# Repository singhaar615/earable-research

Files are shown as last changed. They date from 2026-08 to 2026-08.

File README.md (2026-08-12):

# Earable-Based Sleep Bruxism Detection

Research project developing a low-cost, in-ear wearable ("earable") system to detect and classify sleep bruxism (teeth grinding) using acoustic signal processing. The system captures grinding-related sound via an in-ear MEMS microphone, processes it on an Arduino, and analyzes it in MATLAB to flag grinding severity.

## Overview

Sleep bruxism is typically diagnosed via polysomnography (PSG), which is expensive, lab-based, and inconvenient for longitudinal monitoring. This project explores whether a simple in-ear acoustic sensor can achieve meaningful grinding detection outside a clinical setting: using nothing more than a MEMS microphone, an Arduino, and signal processing techniques adapted from PSG-based bruxism severity research.

The pipeline spans three layers:

- **Hardware**: an Arduino-based in-ear MEMS microphone rig for raw audio data collection
- **Signal processing**: MATLAB scripts for filtering, burst detection, and spectral analysis
- **Classification**: a lightweight warning algorithm that flags grinding events as No Warning / Mild / Severe

## Background & Motivation

Occlusion testing (mic near the jaw vs. mic sealed in-ear) showed that in-ear placement produced a substantially stronger grinding signal than external placement, so all subsequent data collection used in-ear placement.

Detection logic was informed by a review of PSG-based bruxism severity literature, whose burst-detection thresholds and two-factor severity structure (episode count vs. duration) shaped the design of this project's own detection algorithm.

### Key scripts

| Script | Purpose |
|---|---|
| `filtering_algorithm.m` | Detects teeth-grinding bursts from a single acoustic trial. Bandpasses the raw signal to the grinding band, builds an envelope, and flags "active" stretches using an adaptive baseline threshold, scoring each candidate burst on duty cycle and spectral flatness to reject non-grinding noise. Classifies the trial as No/Mild/Severe Warning based on burst count and duration, and plots the time-domain and frequency-domain (Welch PSD) views. |
| `silence_v_fan.m` | Compares the frequency spectrum of grinding recordings made in silence vs. with fan noise present. Concatenates matching Raw (or Filtered) columns per condition across multiple days, computes a Welch PSD for each, and plots the two spectra side by side to check for potential teeth grinding bands and whether fan noise masks or shifts the grinding signature. |
| `updated_fft.ino` | Arduino sketch that samples the earable's microphone at 5 kHz for 150 seconds, tracking a slowly-updating baseline (rolling average) to subtract out DC drift. Applies a fixed noise floor to the deviation from baseline and streams both the raw and processed values over serial as CSV. All data collected from this was used in filtering/analysis in MATLAB. |

## Known Limitations

- Detected grinding duration tracks the correct relative trend across severity tiers but is not numerically precise against ground-truth grinding time
- Classification accuracy has only been validated on a single subject; generalization to other users/ear geometries is untested
- Band selection (20–80 Hz) and thresholds were tuned empirically for this dataset and may need recalibration for other hardware or environments

## Status

This research project has concluded; the repository is preserved as a record of the methodology, pipeline, and findings.

## License

See [LICENSE](LICENSE) for details.

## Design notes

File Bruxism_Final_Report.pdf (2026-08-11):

## A Non-Invasive Acoustic Sensing System for Bruxism Screening

Aaruni Singh
Summer 2026; 2 Credit Hours Mentors: Dr. Saeed Mohammadi, Dr. Babak Ziaie

Abstract—Sleep bruxism (teeth grinding) is a common, frequently undiagnosed oral disorder, and is currently screened using expensive sleep labs or uncomfortable EMG-based devices. This study explores whether a low-cost, in-ear MEMS microphone can detect teeth grinding from acoustic signals and distinguish it from ambient noise. Occlusion-effect testing found that in-ear microphone placement increased grinding-signal amplitude by roughly 10× relative to a near-jaw placement. Using 30-minute grinding recordings under silence and fan noise, a 20–80 Hz frequency band was identified as unique with grinding after excluding peaks shared with non-grinding baseline recordings. A MATLAB-based filtering algorithm using envelope thresholding, gap-bridging, duty-cycle, and spectral-flatness criteria correctly classified all tested trials (3/3 No Warning, 3/3 Mild, 2/2 Severe) for a sample size of one (N = 1). Results support the feasibility of audio-only bruxism screening, though generalization beyond one subject and validation against polysomnography metrics remain future work.

I. INTRODUCTION
A. Background Information

Bruxism (teeth grinding) is a frequently undiagnosed oral disorder that can lead to serious dental damage, poor sleep, and long-term health issues.

- Bruxism (awake or sleep) affects an estimated 24% of adults and 19% of children.
- Sleep bruxism specifically affects an estimated 21% of the global population.

Common causes of bruxism include stress and anxiety, abnormal tooth alignment, certain medications, neurological conditions, and substance abuse. Symptoms include tooth wear and sensitivity, temporomandibular joint (TMJ) pain and stiffness, recurrent headaches or migraines, discomfort in biting or chewing, and poor sleep quality. If untreated over months or years, irreversible damage may occur.

Current diagnosis requires expensive overnight sleep lab stays (polysomnography, or PSG), and existing wearable devices that are uncomfortable and impractical for daily use primarily because movement during sleep disrupts electrode placement in EMG-based wearables.

B. Research Problem or Question

The overarching question is: can bruxism be accurately detected using acoustic signals captured from a patient as they sleep overnight, and can this be accomplished through a low-cost wearable?

This research investigates whether a small microphone placed inside the ear canal can reliably capture the acoustic signatures of oral events and whether teeth grinding frequencies can be distinguished from ambient environmental noise. Following that, the research explores the possibility for an algorithm that flags the severity of teeth grinding based on the audio recordings. It will also lay the groundwork for a low-cost, non-invasive, at-home earable device that could screen for bruxism without requiring clinical settings.

C. Significance of the Research

An audio only approach to bruxism screening has clear practical advantages over existing options, as it avoids the electrode-placement problems tied to EMG sensors, and makes at-home screening accessible at a scale that PSG and EMG-based devices cannot match because it is built with low cost, off-theshelf components. If validated further, this approach could allow for remote monitoring to help track the effects of medication over time, and support early, preventative detection before dental damage occurs. As shown in the device comparison in Section II, most current commercial screening devices remain EMG-based, and this study's fully audio-only approach remains distinctive within that landscape, addressing a gap that has been largely unaddressed to date.

II. LITERATURE REVIEW

A. Overview of Relevant Literature

The current clinical gold standard for diagnosing sleep bruxism is polysomnography (PSG), typically performed with audiovisual recording (PSG-AV) in a sleep lab. While accurate, PSG is expensive, inconvenient for patients, and not scalable for widespread or repeated screening.

Several ambulatory devices have been developed as PSG alternatives. All are EMG based, detecting bruxism via electromyographic, or muscle-activity, signals. Two of the seven devices reviewed in Table I (NOX T3 and Sleep Profiler) additionally include audio recording, but none rely on audio as their primary bruxism detection signal in the way this study's earable design does.

TABLE I
Comparison of Current Commercially Available Ambulatory Bruxism-Screening Devices
Category | Bitestrip | dia-BRUXO | GrindCare | Bruxoff | NOX T3 | Sleep Profiler

Earable (this
study)
EMG-based | X | X | X | X | X | X | —
Audio recording | — | — | — | — | X | X | X
Multi-night capable | — | — | X | X | — | — | X
Sensitivity / Specificity vs. PSG-AV | 72–84.2% / — | Not evaluated | 60% / 60% | 83.3% / 72.2% | 48.3% / 81.2% | 100% / 93.3% | Not evaluated (this study)

Source: Australian Dental Journal (2024)

Polysomnography remains the reference standard but shares the same limitation across all alternatives: expense, inconvenience, and poor scalability for daily use.

B. Key Theories or Concepts

The occlusion effect is an acoustic phenomenon in which sealing the ear canal increases the perceived loudness of bone-conducted, low-frequency sound relative to an open ear. This is because sealing the ear traps and reinforces vibration conducted through the skull and jaw rather than sound traveling through open air (Acta Acustica, 2021).

Related literature supports the physiological basis for this study's acoustic sensing approach. Jaw movement produces bone-conducted acoustic sound that can be captured near the ear canal. Separately, snoring has been shown to produce acoustic signatures that are distinguishable from bruxism grinding, and at least one existing patent describes a device made specifically to sense teeth grinding acoustic signals and to differentiate them from other noise (PubMed, 2025; U.S. Patent, 2025).

Together, this predicts that an in-ear (occluded) microphone should better capture jaw-generated, bone-conducted sounds such as grinding and snapping. This study's own occlusion-effect trial (Sections III and IV) was designed to test this prediction directly for grinding.

III. METHODOLOGY

A. Research Design

An Arduino-interfaced MEMS microphone was used to record acoustic signals near and within the ear canal (Fig. 0). Data collection proceeded in two phases.

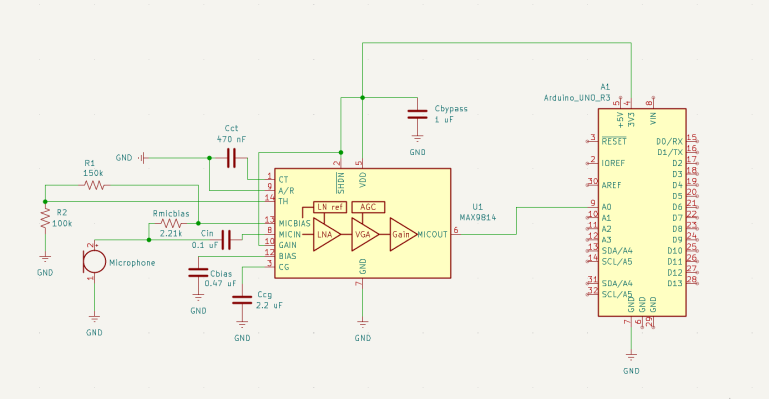
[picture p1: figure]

Fig. 0. Arduino and MEMS microphone circuit used for all recordings (MAX9814 microphone amplifier with automatic gain control, feeding an Arduino Uno analog input).

Phase 1 — Microphone Placement / Occlusion Effect Trial

To determine the optimal microphone placement, three trials of 10 seconds of teeth grinding each were recorded under two placement conditions:

(a) the microphone positioned close to the jaw, outside the ear
(b) the microphone inserted within the ear canal (occluded)

The in-ear placement captured a stronger grinding signal than the near-jaw placement, showing a great increase of roughly 10× in signal amplitude, which is consistent with the occlusion effect described in Section II. Based on this result, the in-ear (occluded) placement was adopted for all subsequent data collection, and additionally offered a more comfortable, secure fit for prolonged wear.

Phase 2 — Grinding and Ambient Noise Characterization

With microphone placement fixed to in-ear, 30 minutes of teeth grinding was recorded under each of two conditions: silence and fan noise. To separate grinding-related frequency content from unrelated background content, an additional 5 minutes of silence only and 5 minutes of fan-noise only baseline audio, with the microphone in the ear, was also collected. To get the desired frequency range, a sample frequency of 5000 Hz was used. Frequency peaks that appeared in both the grinding recordings and the no grinding baseline were treated as artifacts unrelated to grinding and were deemed to likely be powerline/electrical interference and its harmonics.

B. Data Collection & Sample Selection

The researcher/developer served as the only subject (N = 1). Therefore, this study is best understood as an exploratory feasibility study rather than a clinically validated trial. Its purpose is to establish whether acoustic grinding signatures are detectable and distinguishable under controlled conditions, providing a foundation for later multiple subject validation rather than an immediate generalizable model (see Limitations, Section V).

C. Data Analysis Techniques

Data was collected through the Arduino and stored in Excel, then imported into MATLAB. A MATLAB program applied a Fourier Transform and, for display, Welch's method for power spectral density estimation, to convert the acoustic signal into the frequency domain. This was done to identify the dominant frequency components associated with grinding and snapping, and breathing events, and to compare grinding recordings against the silence/fan baselines described above.

Filtering Algorithm Design

Building on the identified grinding frequency band of 20-80 Hz (Section IV), a MATLAB-based classification algorithm was developed to categorize each recording into one of three warning levels: No Warning, Mild Warning, or Severe Warning. The algorithm was evaluated using recordings with known, self-labeled ground truth, consisting of three trials each for each type of warning. The No Warning recordings consisted of normal speech, humming, and little to no teeth grinding, with any grinding activity lasting less than 1 second. The Mild Warning recordings contained occasional short grinding episodes lasting approximately 2–5 seconds. The Severe Warning recordings were characterized by frequent grinding episodes, with grinding activity present for at least 80% of the recording duration. The classification pipeline used to assign each recording to a warning level follows below.

- Signal cleanup: The raw microphone signal is adjusted so that unwanted background offsets and slow changes are removed.
- Envelope extraction: The overall strength of the microphone signal is measured every 50 milliseconds. This helps identify when the sound becomes stronger, such as during possible grinding activity.
- Thresholding: A baseline is decided from the quieter parts of the recording. When the signal strength rises above a set threshold, that section is marked as active and considered a possible grinding event.
- Gap bridging: Very short gaps between active sections are filled in so that one continuous grinding event is not incorrectly divided into several smaller events.
- Burst validation: Each possible grinding event is checked to make sure it is active for a sufficient portion of its duration and has frequency characteristics that are consistent with grinding rather than speech or other sounds.
- Tier decision: The validated grinding events are compared with the duration and frequency requirements for each warning level. A warning is only given when enough evidence is present, which helps prevent a single short or unrelated sound from causing a false warning.

TABLE II
Parameters Used by the Filtering/Classification Algorithm
Parameter | Value | Purpose
Grinding frequency band | 20–80 Hz | Isolates the frequency range identified from the silence condition grinding analysis as most associated with grinding.
Minimum burst duration (Mild floor) | 0.25 s | Filters out short noise blips that are too short to represent a real grinding or clenching event.
Minimum burst duration (Severe floor) | 1.5 s | Minimum cutoff for a sustained grinding episode
Burst threshold multiplier | 2× baseline | Sets how much louder than the quiet baseline a sample must be to count as “active”.
Baseline percentile | Quietest 8% of envelope | Defines the “quiet” reference level
Gap-bridging window | 0.1 s | Combines brief dips inside one continuous grinding stretch so it is not cut up into many small bursts.
Minimum duty cycle | 60% | Rejects bridged stretches that are only sparsely active within their own span

Parameter | Value | Purpose
Minimum spectral flatness | 0.4 | Rejects tonal sounds like speech (flatness near 0) and keeps broadband, noise-like sounds like grinding (flatness near 1).
Minimum corroborating bursts | 2 | Requires at least 2 qualifying bursts before a Mild or Severe warning fires, so a single stray event cannot trigger a false alarm.
D. Expected Outcome / Hypothesis

The target performance benchmark is ≥85% sensitivity and ≥85% specificity relative to PSG, which is defined as:

- Specificity is avoiding false alarms.

Ex. of 100 non-bruxism instances, ≤ 15 incorrectly flagged

- Sensitivity is correctly detecting true events.

Ex. of 50 actual bruxism events, at least 43 correctly detected

This study did not use PSG-labeled ground truth, so formal sensitivity/specificity against PSG could not be found in this round (see Limitations, Section V). Instead, the classification algorithm's tier decisions were validated against the known, self-labeled ground truth of each recorded trial, or trials that are purposefully done to get a specific warning label.

IV. RESULTS

Findings are presented in three groups:

(1) the microphone placement / occlusion effect trial
(2) frequency-domain comparison of grinding vs. ambient noise
(3) output of the filtering/classification algorithm

Fig. 1: Occlusion Effect Trial — Near-Jaw vs. In-Ear Placement

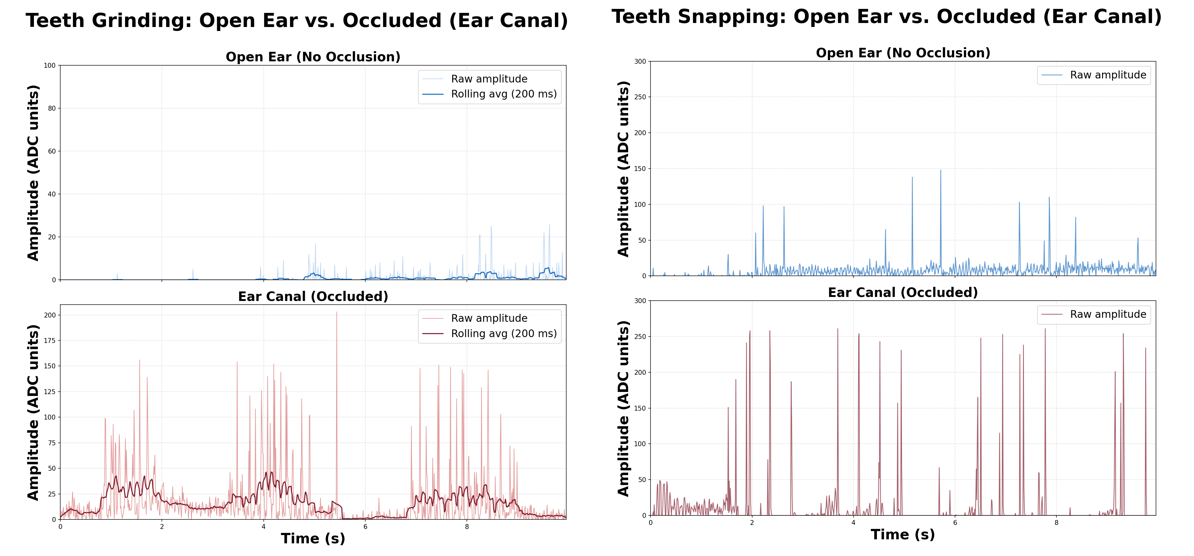
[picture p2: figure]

Fig. 1. Comparison of grinding signal amplitudes under each microphone placement

Fig. 2: Baseline Frequency Content — Silence vs. Fan Noise (No Grinding, In-Ear)

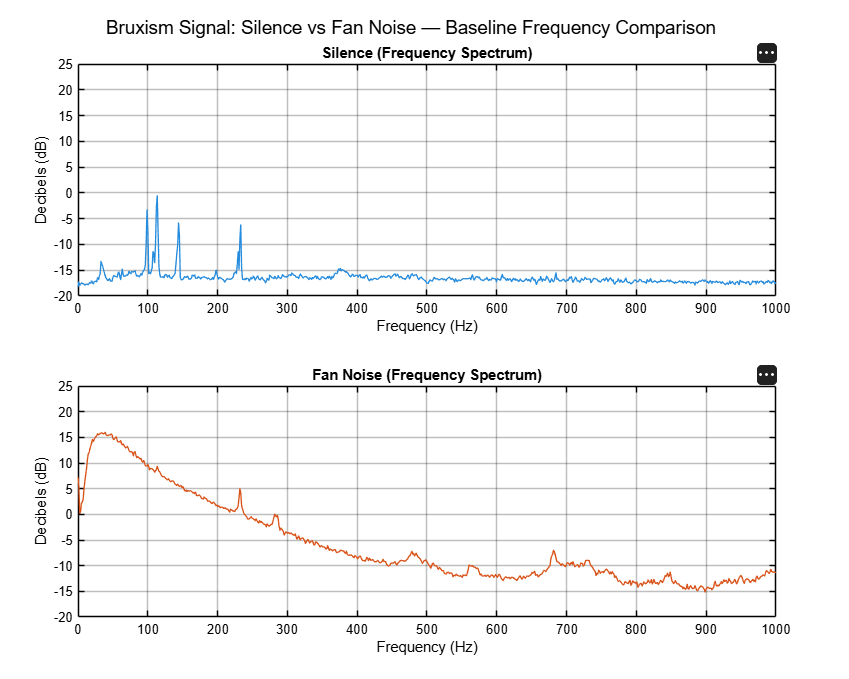
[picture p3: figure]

Fig. 2. Frequency domain comparison of 5 minutes of silence and 5 minutes of fan noise, with the microphone in-ear and no grinding. Peaks present here (approximately 110, 140, and 230 Hz, with an additional 285 Hz peak under fan noise) are not related to grinding and are most likely powerline/electrical interference and its harmonics and can be dismissed as non-grinding artifacts.

Fig. 3: Teeth Grinding Frequency Content — Silence vs. Fan Noise (In-Ear)

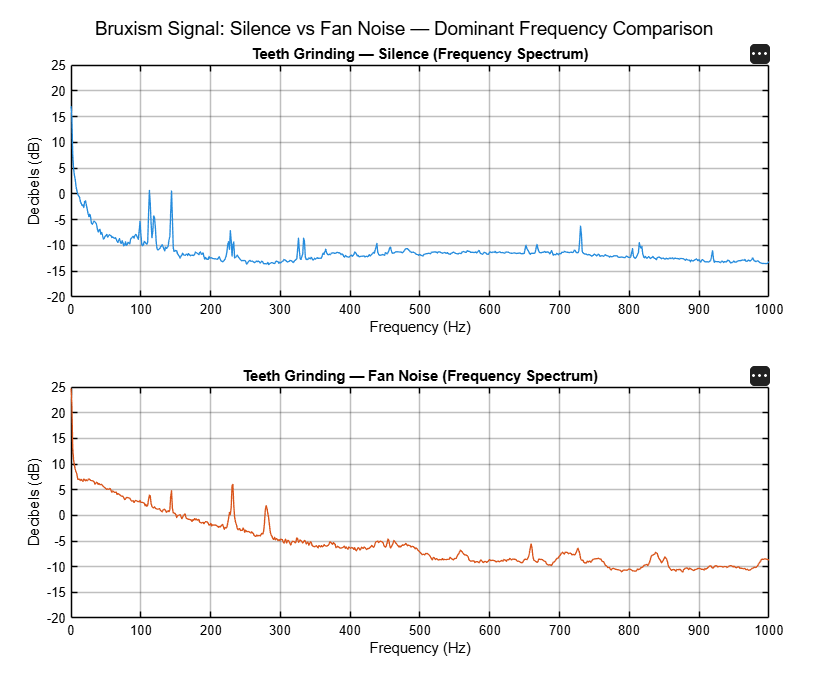
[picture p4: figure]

Fig. 3. Frequency domain comparison of 30 minutes of teeth grinding recorded in silence and 30 minutes recorded under fan noise. Peaks shared with the no grinding baseline (Fig. 2) are treated as non-grinding artifacts. The 20–80 Hz band is distinct between grinding and non-grinding activity and was used as the target band for the filtering algorithm (Section III).

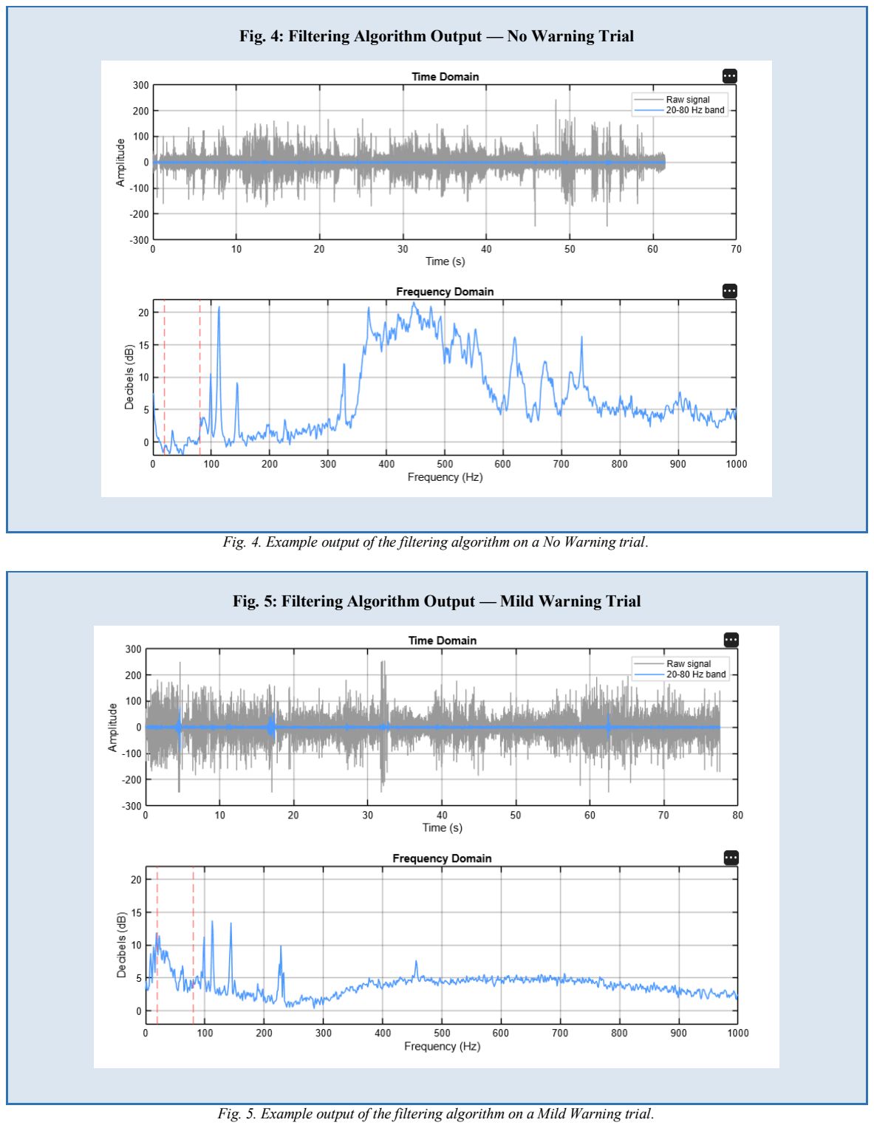
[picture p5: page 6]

Fig. 4: Filtering Algorithm Output — No Warning Trial

Fig. 4. Example output of the filtering algorithm on a No Warning trial.

Fig. 5: Filtering Algorithm Output — Mild Warning Trial

Fig. 5. Example output of the filtering algorithm on a Mild Warning trial.

Fig. 6: Filtering Algorithm Output — Severe Warning Trial

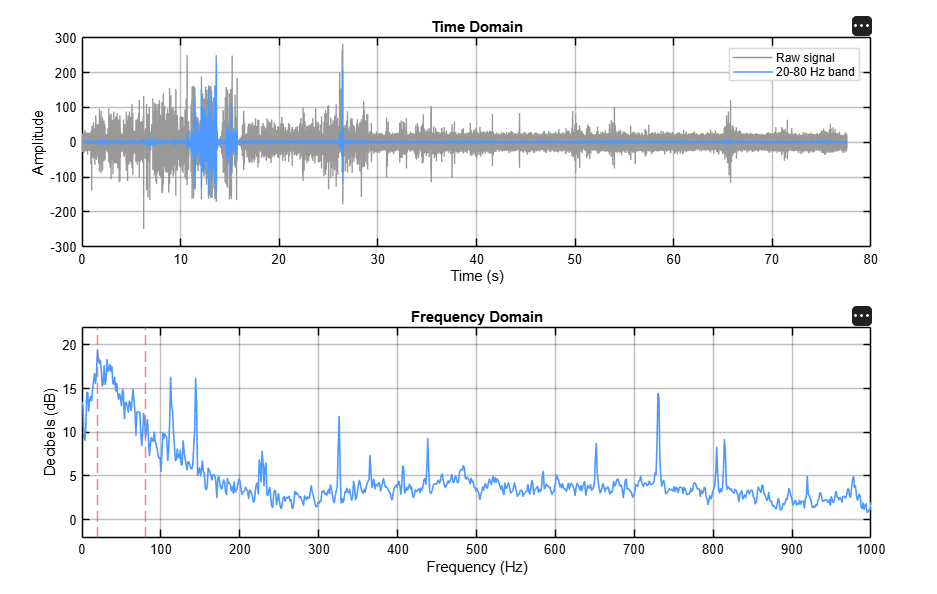
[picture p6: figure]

Fig. 6. Example output of the filtering algorithm on a Severe Warning trial

Classification Statistics
The filtering algorithm correctly classified every trial test. Table III summarizes the average statistics the algorithm computed for each tier.

TABLE III
Averaged Classification Statistics by Warning Tier

Statistic

No
Warning
(Avg, Trials
1–3)

Mild (Avg,
Trials 1–3) | Severe | What It Measures & Why It Matters
Recording Duration (s) | 72.3 s | 77.5 s | 77.5 s | Average length of the analyzed recordings
Baseline Envelope Level | 7.46 | 7.37 | 7.62 | Quietest 8% of the recording; noise floor as reference point.
Detection Threshold (Amplitude) | 14.93 | 14.73 | 15.25 | Envelope level a sample must exceed to be flagged as an active, possible-grinding sample.
Total Active Time in Grinding Band | 32.5 s | 12.0 s | 29.8 s | Total time the envelope stayed above threshold; raw measure of loud activity before burst-validity filtering.
Active Time Percentage | 36.1% | 15.3% | 38.3% | Active time from the whole recording, making trials of different lengths directly comparable.
Number of Bursts Clearing Mild Length Floor (≥0.25 s) | 0.3 | 7.0 | 10.7 | Count of active stretches long enough to be a real event rather than noise. Feeds into the Mild/Severe decision.
Number of Bursts Clearing Severe Length Floor (≥1.5 s) | 0 | 0.3 | 2.7 | Count of sustained bursts meeting the duration cutoff for a bruxism episode; feeds into the Severe decision.
Longest Continuous Grinding Activity | 0.16 s | 1.39 s | 4.04 s | Duration of the single longest qualifying burst — captures the most intense episode, which the total active-time figure alone can hide.

One notable pattern in Table III is that the No Warning trials show more raw active time (32.5 s) than the Mild trials (12.0 s). This is expected, because that statistic counts all envelope-threshold crossings before burst-validity filtering is applied, so it can be inflated by non-grinding activity like speech. The burst-count and duration statistics computed after duty-cycle and spectral-flatness filtering increase consistently from No Warning to Mild to Severe, which is why the algorithm's tier decision is based on those validated burst statistics rather than on raw active time alone.

More generally, the absolute values the algorithm reports for detected grinding time do not precisely match the actual physical grinding time in each trial. However, the validated burst statistics still follow the correct relative trend across tiers (increasing from No Warning to Mild to Severe), which is what the tier-classification logic relies on, and is consistent with the 3/3 classification accuracy reported above.

V. DISCUSSION
A. Interpretation of Results
- Teeth grinding produced clear, distinguishable acoustic signatures, confirming that jaw-generated sounds can be reliably captured near or within the ear.
- Occluding the ear canal with an in-ear microphone increased grinding-signal amplitude by roughly 10× relative to a near-jaw, non-occluded placement, directly confirming the occlusion-effect prediction from Section II and determining the switch to in-ear placement for all subsequent testing.
- The 20–80 Hz band, isolated after excluding peaks shared with the no-grinding baseline, was identifiable under both silence and fan-noise conditions.
- Although the the algorithm's active-time and burst-duration values did not align to the ground truth, the relative trend follows across the tiers and shows feasibility for a more accurate model.

Together, these results indicate that ear-canal occlusion improves acoustic sensitivity to grinding activity specifically, making occlusion a useful design strategy for wearable, earlevel bruxism sensing.

B. Comparison to Previous Studies

Unlike the EMG-based devices reviewed in Section II, this approach avoids the electrode-placement reliability problem that limits EMG devices during overnight use. Because the system uses low-cost, off-the-shelf components it also shows stronger potential for accessibility than PSG or the reviewed EMG-based alternatives, which require either a clinical setting or specialized hardware. This study's empirical result provides a quantified confirmation in the specific context of teethgrinding detection using acoustic signals.

C. Implications & Limitations

This approach shows strong potential for accessible, low-cost, early detection of bruxism outside of clinical sleep lab environments, and could plausibly extend toward broader sleep-event screening using the same acoustic sensing pipeline.

A major limitation of this study was the sample size as a single subject (N = 1) throughout. All trials were classified correctly for this subject, but this is not enough evidence that the same frequency band, thresholds, or accuracy will generalize to other people. Another major limitation is tied to the acoustic signal approach itself, as the current system does not detect nonacoustic clenching, which is a clinically relevant subtype of bruxism. Due to the controlled settings of this study, filtering out movement artifacts from the target grinding signal remains a challenge not yet fully solved. Furthermore, no PSG-labeled ground truth was used, so sensitivity/specificity against the clinical reference standard has not yet been measured and will serve as a critical point of concern for the future of this study. Other practical constraints, such as user comfort, battery life, and sufficient clinical testing are prominent research problems before this could move toward a deployable product.

VI. CONCLUSION

A. Summary

This study found that teeth grinding produces acoustic signals that are reliably detectable within the ear canal, with the in-ear (occluded) microphone placement improving grinding signal capture by roughly 10× relative to a near-jaw placement. After identifying a 20–80 Hz grinding-associated frequency band and excluding peaks shared with non-grinding baseline recordings, a MATLAB-based filtering algorithm using envelope thresholding, gap-bridging, duty-cycle, and spectral-flatness criteria correctly classified all tested trials into the correct warning tier for this subject. Formal sensitivity and specificity against a PSG reference standard were not evaluated in this round and remain a target for future work.

B. Contributions

This work demonstrates a low-cost, non-invasive, audio-only alternative to existing largely EMG-based bruxism screening devices, addressing a gap identified in Section II, since none of the devices reviewed use acoustic sensing as their primary detection method. It also provides an early, quantified result for how ear-canal occlusion affects signal capture, which can inform future earable sensor design beyond bruxism specifically, along with a working, fully documented filtering algorithm and parameter set that can be extended or re-tuned for future subjects.

C. Future Research
- Validate the filtering algorithm and frequency band on additional subjects to assess generalizability beyond N = 1.
- Measure true sensitivity and specificity against the ≥85%/≥85% benchmark (Section III).
- Use pattern recognition or machine learning algorithms to efficiently flag irregularities given a more diverse dataset.
- Refine the prototype for improved comfort, size, and consistency to support reliable overnight use.
- Run tests in natural (home) conditions, with a larger sample, to assess feasibility beyond controlled lab testing.

VII. REFERENCES

[1] Carillo, Kevin, and Olivier Doutres. “On the Removal of the Open Earcanal High-Pass Filter Effect Due ...” On the Removal of the Open Earcanal High-Pass Filter Effect Due to Its Occlusion: A Bone-Conduction Occlusion Effect Theory, 29 July 2021, actaacustica.edpsciences.org/articles/aacus/abs/2021/01/aacus210015/ aacus210015.html.
[2] Lavigne, G J et al. “Sleep bruxism: validity of clinical research
diagnostic | criteria | in | a | controlled | polysomnographic
study.” Journal of dental research vol. 75,1 (1996): 546-52.
[3] Li, C et al. “Ambulatory devices to detect sleep bruxism: a narrative review.” Australian dental journal vol. 69 Suppl 1,Suppl 1 (2024): S53-S62.
[4] Rosar, João Vicente et al. “Identifying predictive factors for sleep bruxism severity using clinical and polysomnographic parameters: a principal component analysis.” Journal of clinical sleep medicine : JCSM : official publication of the American Academy of Sleep Medicine vol. 17,5 (2021): 949-956. doi:10.5664/jcsm.9078
[5] Takamura, Ryo et al. “A Study on the Detection of Sleep Bruxism Using Acoustic Features.” 2025 IEEE International Symposium on Consumer Technology (ISCT) (2025): 97-101.
[6] Zieliński, Grzegorz et al. “Global Prevalence of Sleep Bruxism and Awake Bruxism in Pediatric and Adult Populations: A Systematic Review and Meta-Analysis.” Journal of clinical medicine vol. 13,14 4259. 22 Jul. 2024, doi:10.3390/jcm13144259

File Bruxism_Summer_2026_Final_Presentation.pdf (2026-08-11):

7/30

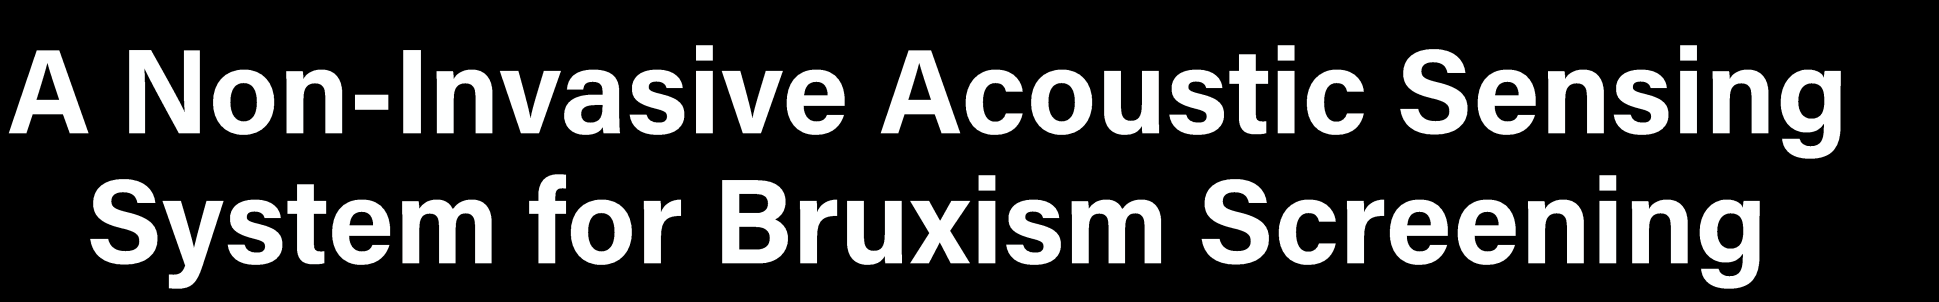
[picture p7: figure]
A Non -Invasive Acoustic Sensing System for Bruxism Screening

What is Bruxism?
Research Objective
Methods
Results
What does this mean for Us? Conclusions

2

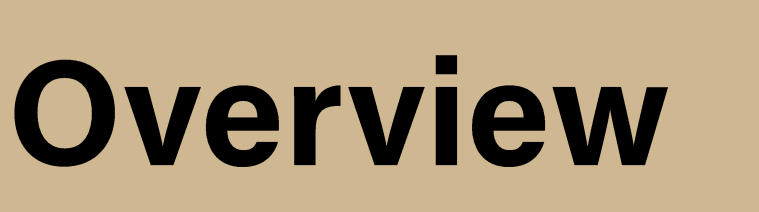
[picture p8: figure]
Overview

## What is Bruxism?

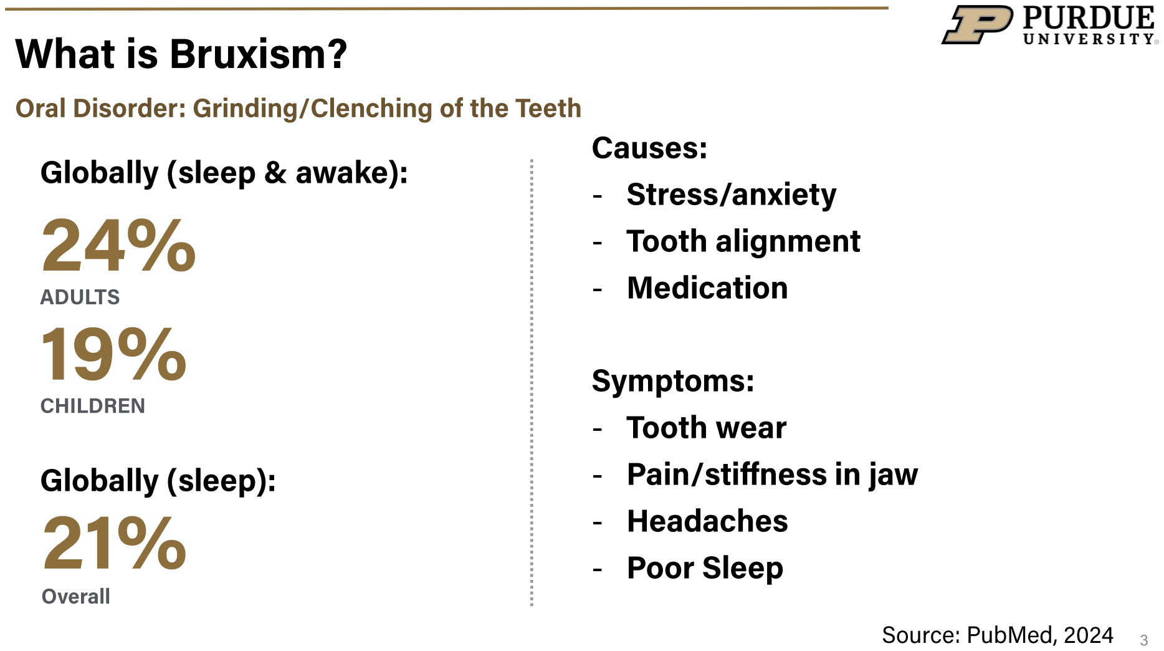
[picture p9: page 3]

Oral Disorder: Grinding/Clenching of the Teeth

### Globally (sleep & awake):

24%
19%

ADULTS

CHILDREN

### Causes: - Stress/anxiety - Tooth alignment - Medication

### Symptoms: - Tooth wear - Pain/stiffness in jaw

- Headaches 21% | - Poor Sleep

Overall

### Globally (sleep):

Source: PubMed, 2024

### Can we accurately detect bruxism using acoustic signals from a patient

### Can this be accomplished through a low -cost wearable?

### - Early detection

### Polysomnography (PSG) or Commercial Devices:

| Bitestrip | dia -BRUXO | GrindCare | Bruxoff | NOX T3 | Sleep Profiler | Earable
EMG -based | X | X | X | X | X | X
Audio recording | | | | | X | X | X
Multi-night capable | | | X | X | | | X
Sensitivity / Specificity vs PSG -AV | 72–84.2% / — | not evaluated | 60% / 60% | 83.3% / 72.2% | 48.3% / 81.2% | 100% / 93.3% | not evaluated

Source: Australian Dental Journal, 2024

“The occlusion effect is commonly experienced by in -ear device wearers as an increased loudness sensation of bone -conducted low frequency sounds.” (Acta Acustica, 2021)

## Acoustic Approach for Bruxism Detection:

“A Study on the Detection of Sleep Bruxism Using Acoustic Features “ found that snoring produces acoustic signatures distinguishable from bruxism. (PubMed, 2025)

A device is "configured to sense acoustical signals generated by teeth grinding" and "perform signal processing to differentiate between teeth grinding and other acoustical signals" (US Patent, 2025)

## Prototype VS Final Project

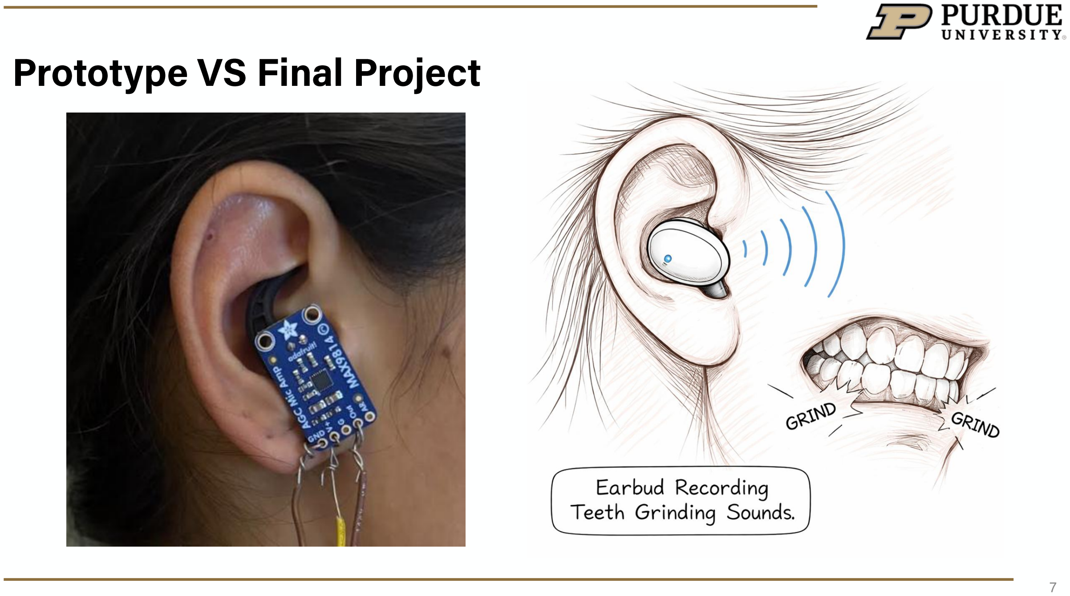
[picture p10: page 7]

## Methods

## Sample Size: N=1 (The researcher)

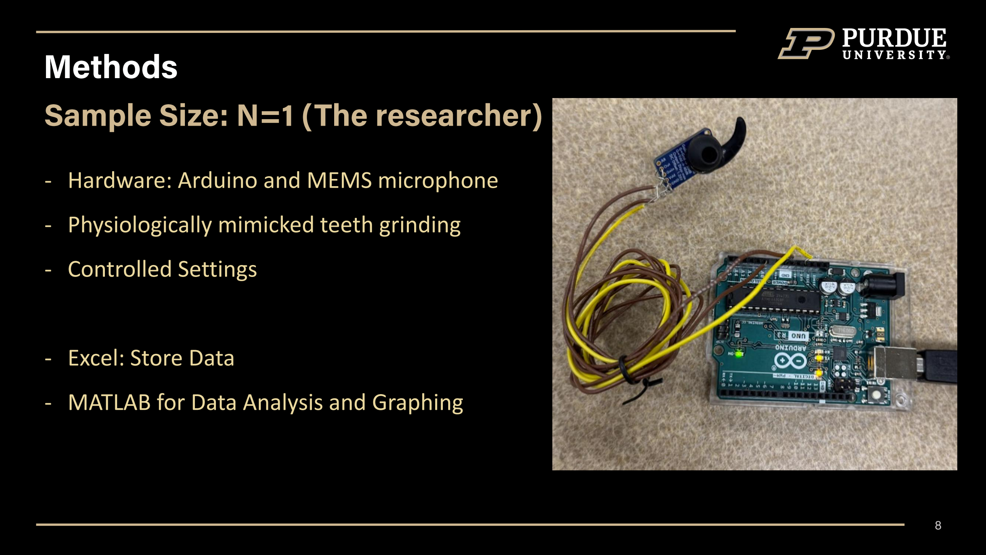
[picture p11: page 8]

### - Hardware: Arduino and MEMS microphone

### - Physiologically mimicked teeth grinding

### - Controlled Settings

### - Excel: Store Data

### - MATLAB for Data Analysis and Graphing

## Occlusion Effect Trial:

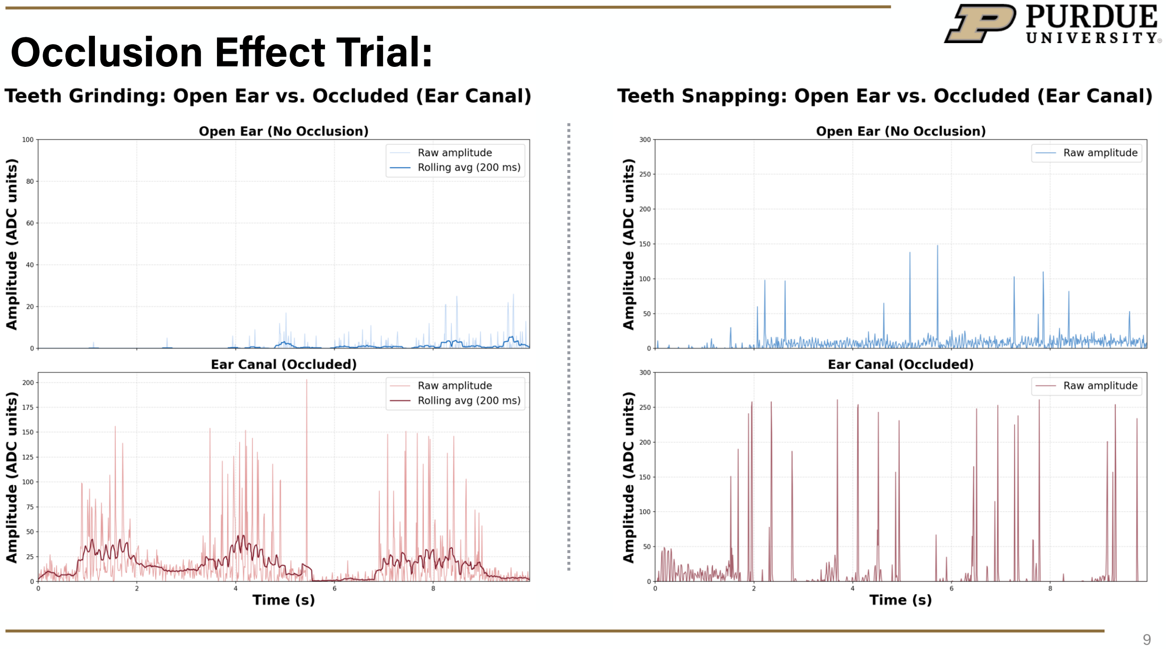
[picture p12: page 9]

- Text or photo

## Acoustic Approach:

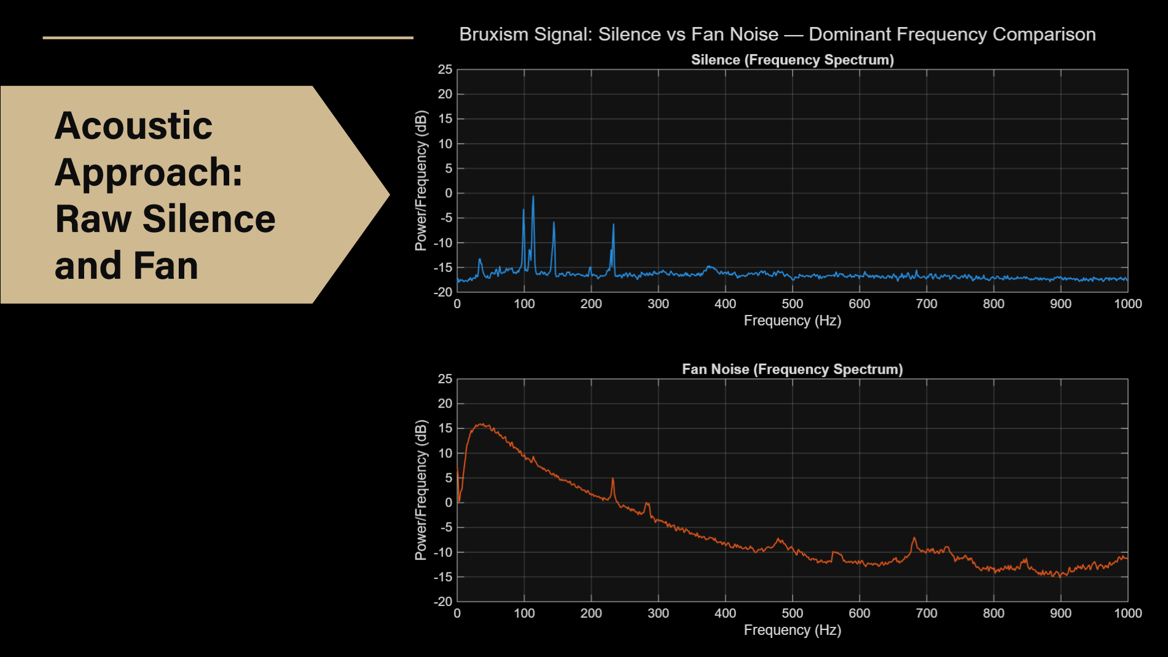
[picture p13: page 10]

## Raw Silence and Fan

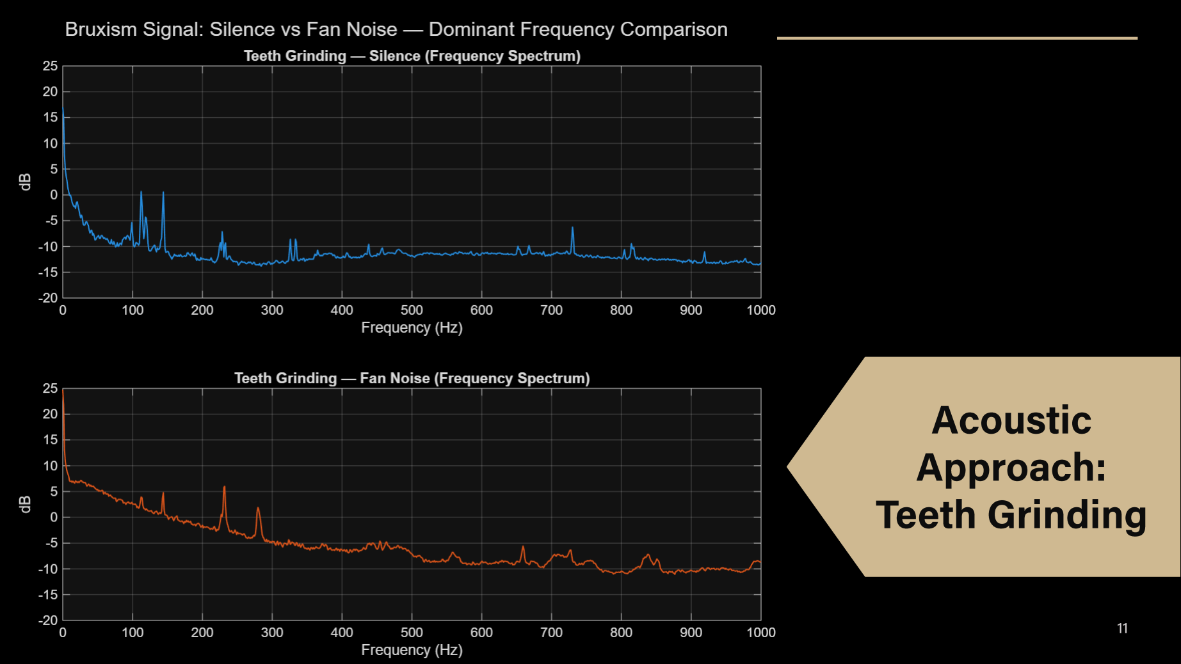
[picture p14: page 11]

## Acoustic Approach: Teeth Grinding

ACOUSTIC APPROACH:

- Grinding -in-silence: ~110, 140, 230, 285 Hz
- Possible range for teeth grinding: [20 –80 Hz]
- Fan noise interfered with grinding detection stronger occlusion needed

OCCLUSION EFFECT:

- Useful Strategy

## Filtering

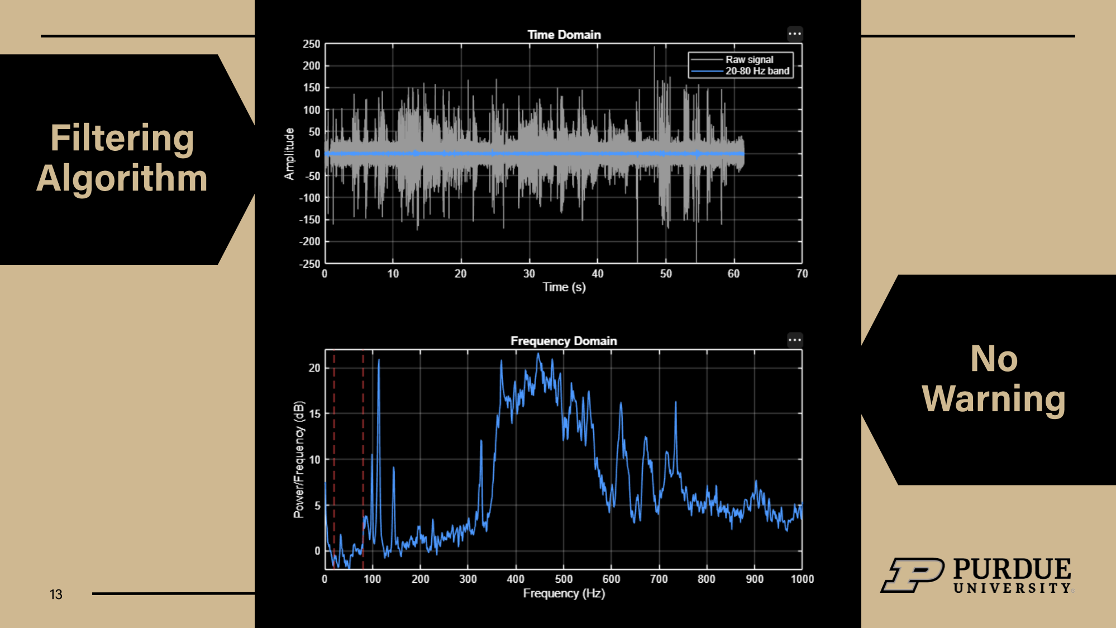
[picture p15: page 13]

No

## Warning

## Algorithm

## Filtering

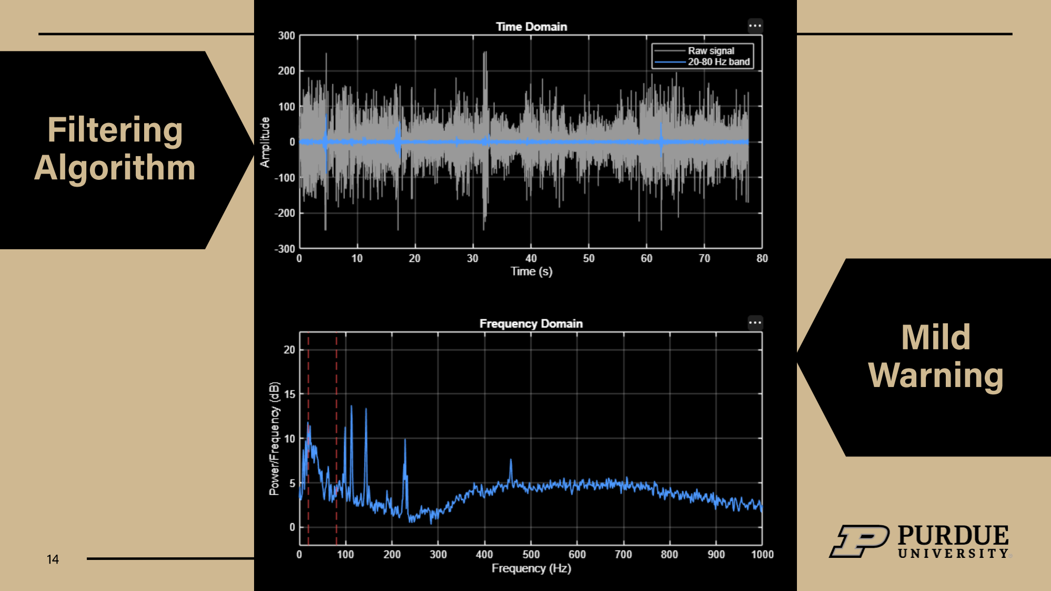
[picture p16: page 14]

## Algorithm

## Mild Warning

## Filtering

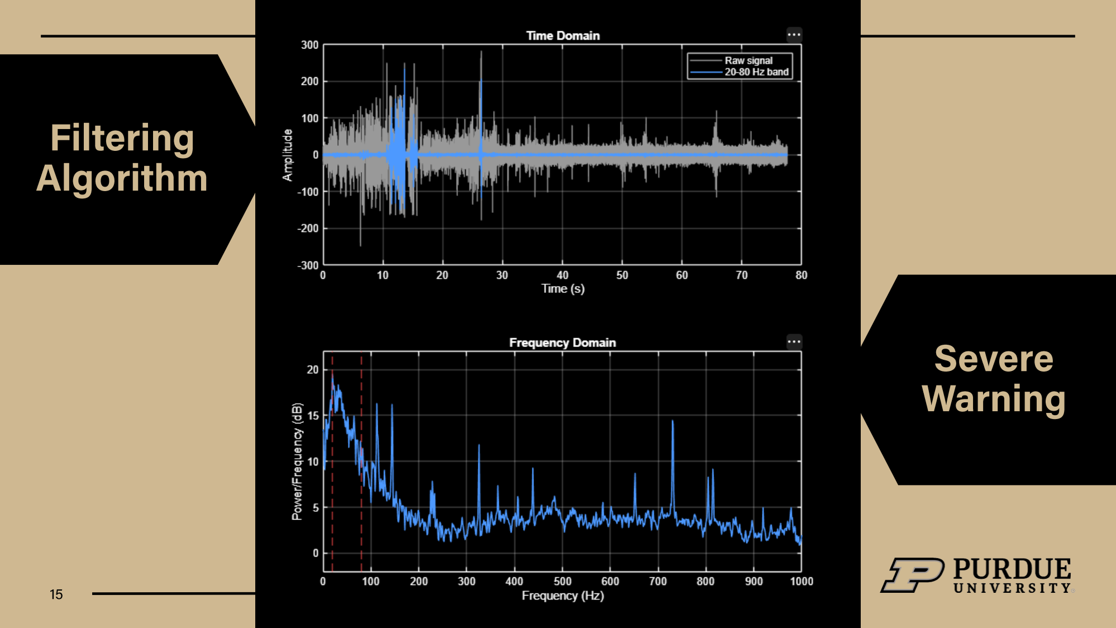
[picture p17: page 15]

## Algorithm

## Severe Warning

## Discussion

No Warning | Mild | Severe
Accuracy | 3/3 | 3/3 | 3/3
Total Active Time in Grinding Band | 32.5 s | 12.0 s | 35.8 s
Number of Bursts Clearing Mild Length Floor ( ≥0.25 s) | 0.3 | 7.0 | 10.7
Number of Bursts Clearing Severe Length Floor ( ≥1.5 s) | 0 | 0.3 | 2.7
Longest Continuous Grinding Activity | 0.16 s | 1.39 s | 4.04s

- Sample size
- Ear-bud Fit
- Filtering out movement artifacts
- Consider new findings
- Use pattern recognition algorithms / machine learning
- Run clinical tests in natural conditions to assess feasibility beyond controlled lab testing

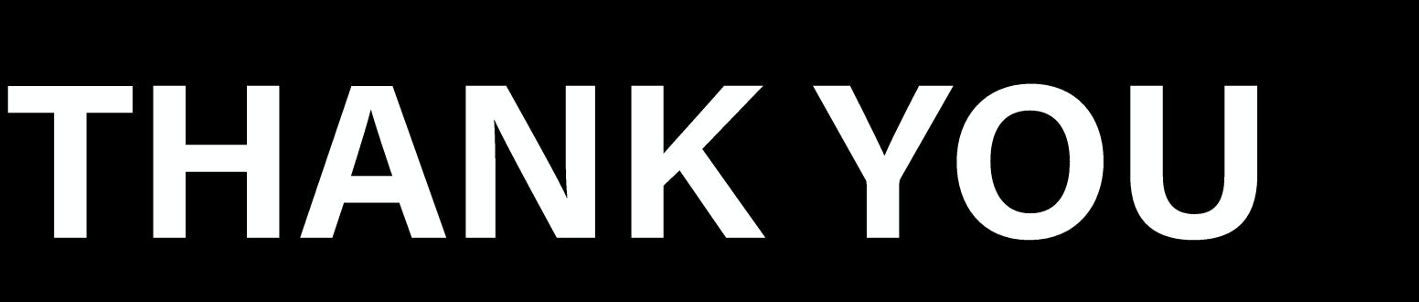
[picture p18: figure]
THANK YOU

### Mentors: Dr. Saeed Mohammadi, Dr. Babak Ziaie

Fourier Transform : converts signal into its frequency components, showing frequencies present and their amplitudes

MEMS: Micro -Electro -Mechanical Systems

Sensitivity: how well your system detects true events

Specificity: how well your system avoids false alarms

Harmonic: a frequency that is an integer multiple of a fundamental frequency (ex. 60 (fundamental), 120, 180 Hz)

Broadband : signal containing many different frequencies at the same time without a specific pitch

Tonal: a sound built around a single clear frequency

## Terms

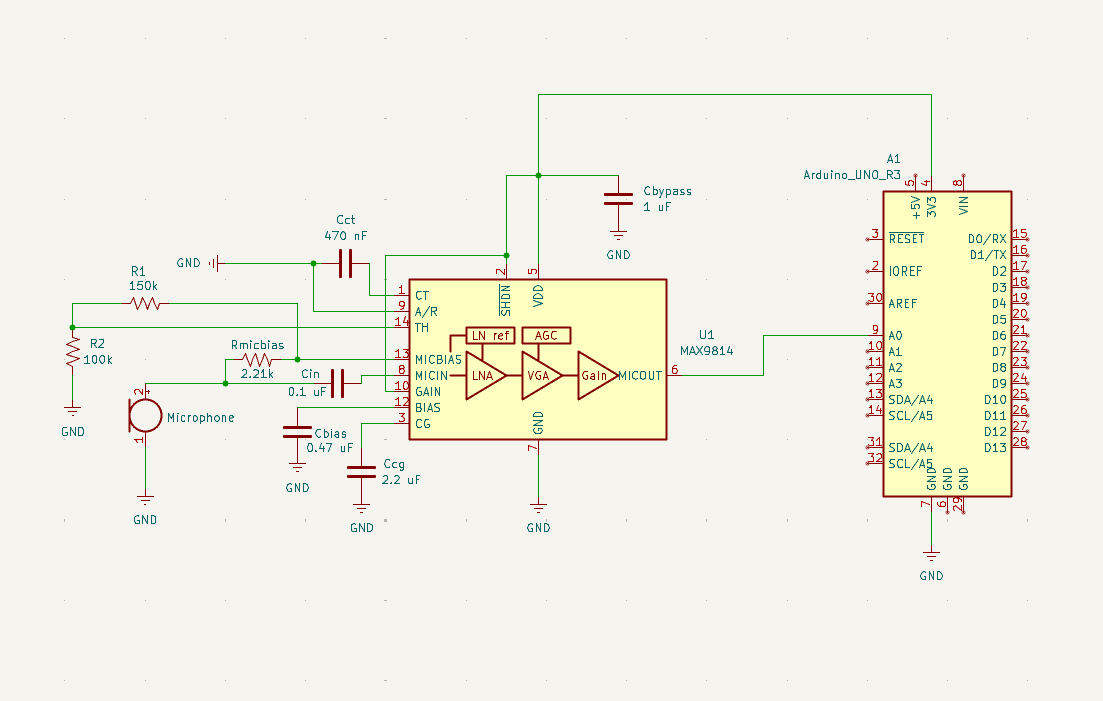
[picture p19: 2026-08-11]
Schematics/Earable/Earable.png

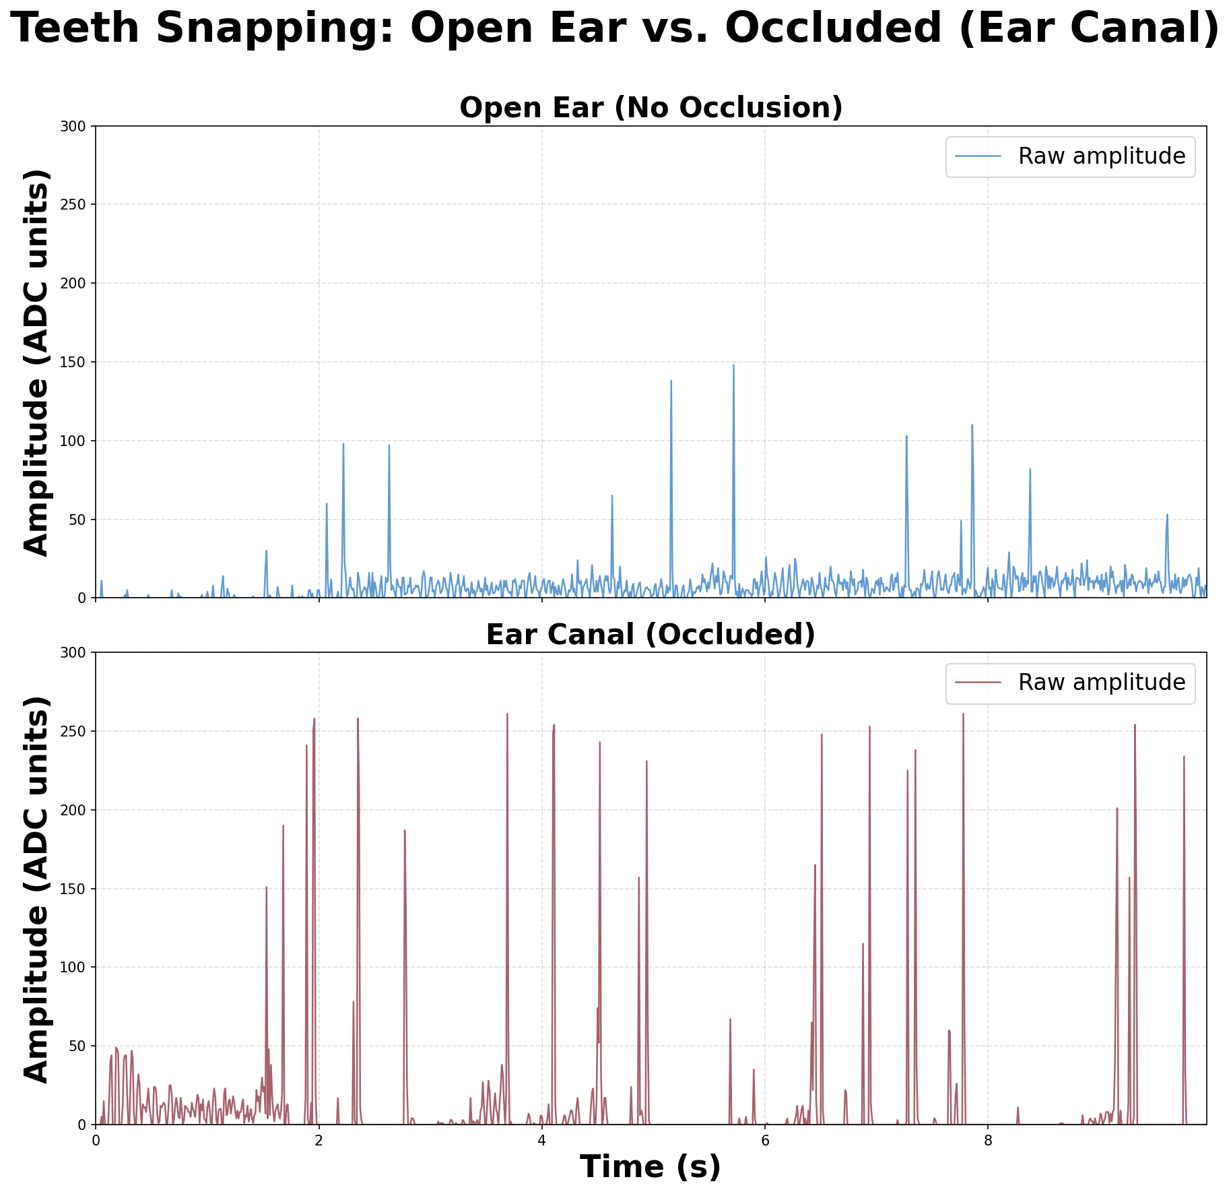
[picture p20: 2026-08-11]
Occulsion Effect/snapping_comparison.png

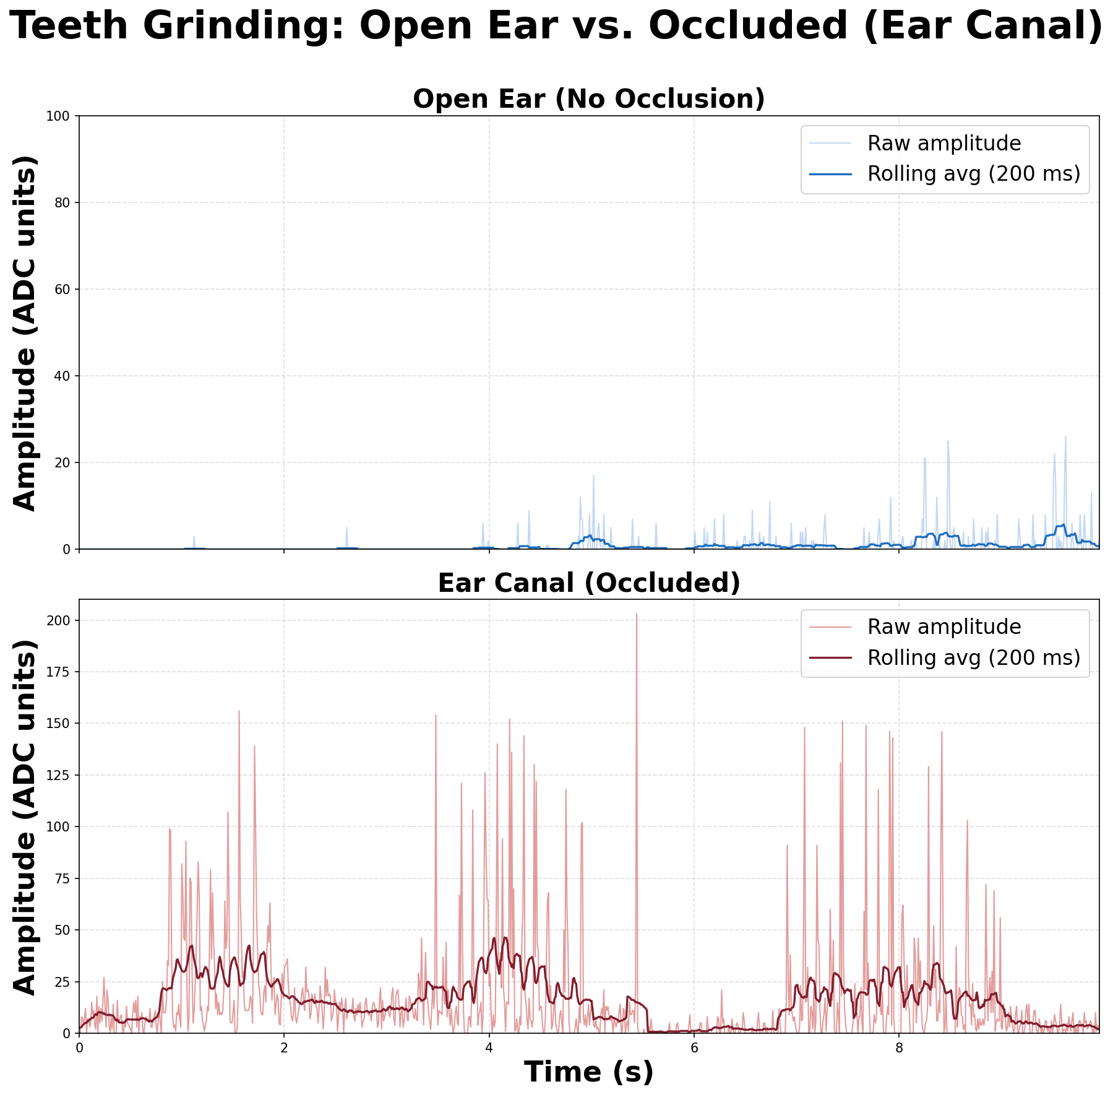
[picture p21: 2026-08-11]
Occulsion Effect/grinding_comparison.png

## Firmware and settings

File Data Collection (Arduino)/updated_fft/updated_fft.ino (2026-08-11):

const int MIC_PIN = A0;

//sampling settings
const unsigned long SAMPLE_PERIOD = 200;         //200 us = 5 kHz
const unsigned long RECORD_TIME = 150000000UL;   //150 seconds

//baseline settings
int baseline = 0;
const int NOISE_FLOOR = 5;

unsigned long startTime;
unsigned long lastSample;
unsigned long lastBaselineUpdate;

void setup()
{
    Serial.begin(1000000);

    //allow microphone to stabilize
    delay(3000);

    //baseline calibration
    long sum = 0;

    for (int i = 0; i < 500; i++)
    {
        sum += analogRead(MIC_PIN);
        delay(2);
    }


    baseline = sum / 500;

    //wait for key press to start recording
    while (Serial.available() == 0)
    {
        //wait
    }

    while (Serial.available())
    {
        Serial.read();
    }

    startTime = micros();
    lastSample = startTime;
    lastBaselineUpdate = millis();
}

void loop()
{
    unsigned long now = micros();

    //stop after record time
    if (now - startTime >= RECORD_TIME)
    {
        while (1);
    }

    //sample at 5 kHz
    if (now - lastSample >= SAMPLE_PERIOD)
    {
        lastSample += SAMPLE_PERIOD;

        //raw sample
        int rawSample = analogRead(MIC_PIN);

        //update baseline slowly every 5 ms
        if (millis() - lastBaselineUpdate >= 5)
        {
            baseline =
                (baseline * 99 + rawSample) / 100;

            lastBaselineUpdate = millis();
        }

        //compute deviation from baseline
        int processed =
            abs(rawSample - baseline) - NOISE_FLOOR;

        if (processed < 0)
        {
            processed = 0;
        }

        //output:
        //raw,processed
        Serial.print(rawSample);
        Serial.print(",");
        Serial.println(processed);
    }
}

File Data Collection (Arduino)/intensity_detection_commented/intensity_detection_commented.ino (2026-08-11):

const int MIC_PIN = A0;           //out signal from MIC
const int SAMPLE_TIME = 10;       //time window to calculate sound intensity (ms)

unsigned long millisCurrent;      //current time stamp
unsigned long millisLast = 0;     //last time stamp since previous value printed
unsigned long millisElapsed = 0;  //time since last print

int baseline = 0;                 // "silence"
int sampleBufferValue = 0;        //max deviation in sample window

const int NOISE_FLOOR = 60;       //approx. noise to subtract later

void setup() {
  Serial.begin(115200);           //start serial communication

  long sum = 0;                   //temp variable summing readings

  //200 samples of silence for baseline
  for (int i = 0; i < 200; i++) {
    sum += analogRead(MIC_PIN);   //sum mic values
    delay(5);                     //delay so measure 1 second of silence
  }
  baseline = sum / 200;           //avg value --> baseline
}

void loop() {
  millisCurrent = millis();       //get current time
  millisElapsed = millisCurrent - millisLast;  //calculate time elapsed from last --> current

  int sample = analogRead(MIC_PIN);   //get current mic signal

  //baseline adjusts over time
  //99% of old + 1% of new --> subtly move towards sample
  baseline = (baseline * 99 + sample) / 100;

  int deviation = abs(sample - baseline); //distance between baseline and sound intensity

  //assign max value immediately
  if (deviation > sampleBufferValue) {
    sampleBufferValue = deviation;
  }

  //only runs if hit 10 ms mark
  if (millisElapsed >= SAMPLE_TIME) {
    int output = sampleBufferValue - NOISE_FLOOR;  //subtract noise
    if (output < 0) output = 0;

    //force fixed y-axis on serial plotting
    Serial.print(0);              //min y axis value (plotted constant)
    Serial.print(" ");      
    Serial.print(300);            //max y axis value (plotted constant)
    Serial.print(" ");
    Serial.println(output);       //mic signal

    sampleBufferValue = 0;        //reset
    millisLast = millisCurrent;   //update last timestamp
  }
}
